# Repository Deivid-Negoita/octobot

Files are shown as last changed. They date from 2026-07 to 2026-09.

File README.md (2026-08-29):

# Octobot

An eight-legged walking robot with 24 servos, built end to end. The chassis and
legs are CAD. A custom ATmega32U4 board drives every servo. A browser workbench
rigs the CAD model and solves its inverse kinematics.

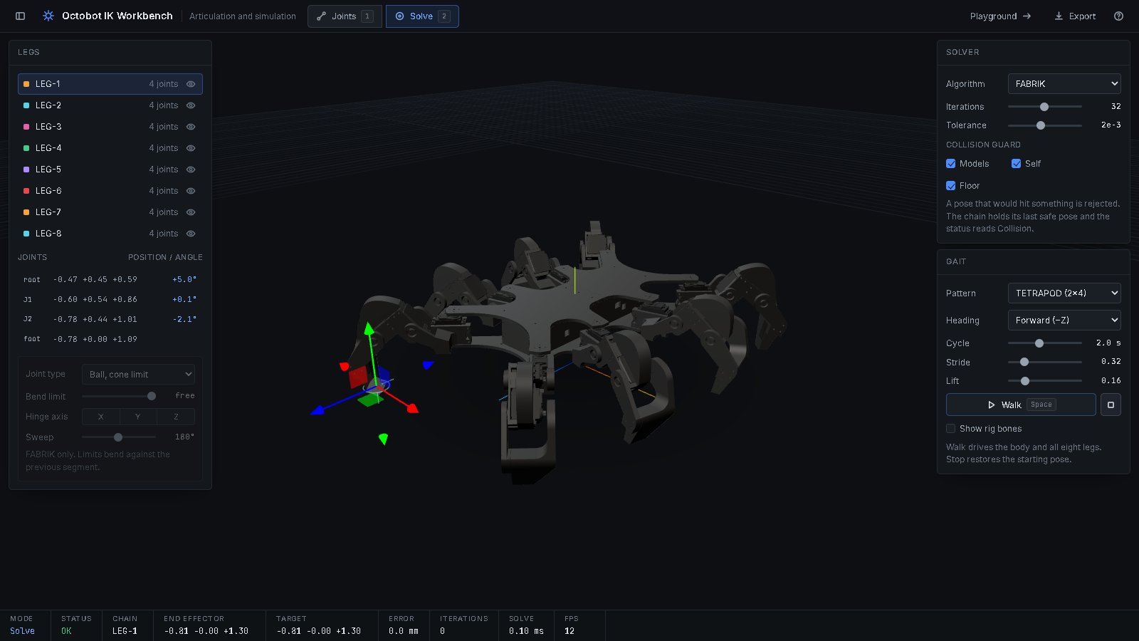
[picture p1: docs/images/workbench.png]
The IK workbench with the octobot rigged into eight legs


**The workbench runs live in the browser:
<https://deivid-negoita.github.io/octobot/>**. It needs no install and no
build step.

The robot carries environmental-monitoring, 3D-scanning and speleological
payloads. Those payloads need the legs to place feet accurately on uneven
ground, which a fixed gait cannot do. The kinematics workbench in this
repository exists to solve that.

---

## What is here

| Folder | Contents |
|---|---|
| [`kinematics/`](kinematics/) | Browser workbench and locomotion sandbox. Three.js, no build step. |
| [`hardware/`](hardware/) | KiCad 7 project for the 24-channel servo control board. |
| [`mechanical/`](mechanical/) | STEP exports of the chassis and a single leg. |
| [`docs/`](docs/) | [Hardware notes](docs/hardware.md), [kinematics notes](docs/kinematics.md) and the [bill of materials](docs/bom.md). |

The embedded firmware lives in a separate repository and is not included here.

---

## Run the kinematics workbench

The workbench runs in the browser with nothing to install:
**<https://deivid-negoita.github.io/octobot/>**. It is a static site, published
from `kinematics/` by `.github/workflows/pages.yml` on every push to `main`. A
fork gets its own copy after enabling **Settings → Pages → Source → GitHub
Actions** once.

To run it locally instead: the pages load ES modules, so they need an HTTP
server. Opening `index.html` from the filesystem gives you a blank screen and a
CORS error in the console.

```bash
cd kinematics/tools
python serve.py          # or double-click start.bat on Windows
```

Open <http://localhost:8123>. The chassis mesh is about 12 MB, so the first load
takes a few seconds. A progress bar reports the download.

Two pages share the model:

**`index.html`, the IK workbench.** The CAD model rigs itself on startup. The
loader finds the feet from the mesh geometry, then builds a hip-yaw →
shoulder-pitch → knee-pitch chain per leg on the real servo shaft axes. It binds
every servo, bracket and casing to the link it is screwed to. You get eight
chains named `LEG-1` to `LEG-8`. Drag the cyan target and that leg solves toward
it in real time while the servo angles update. Press `Space` to run a gait.

**`playground.html`, the locomotion sandbox.** Drive the robot with `W A S D` over
terrain blocks you spawn and drag. The feet land on the block surface or the
ground by analytic sampling, and the body rides at the average support height.
Live servo angles for all 24 joints stream into the telemetry panel.

| Key | Action |
|---|---|
| `1` / `2` | JOINTS / SOLVE mode (workbench) |
| `Space` | start or stop walking (workbench) |
| `H` | open the help card (workbench) |
| `P` | show or hide the panels (both pages) |
| `W A S D` | walk (playground) |
| `Q` / `E` | lower or raise the body (playground) |
| `Y` | toggle the onboard camera view (playground) |

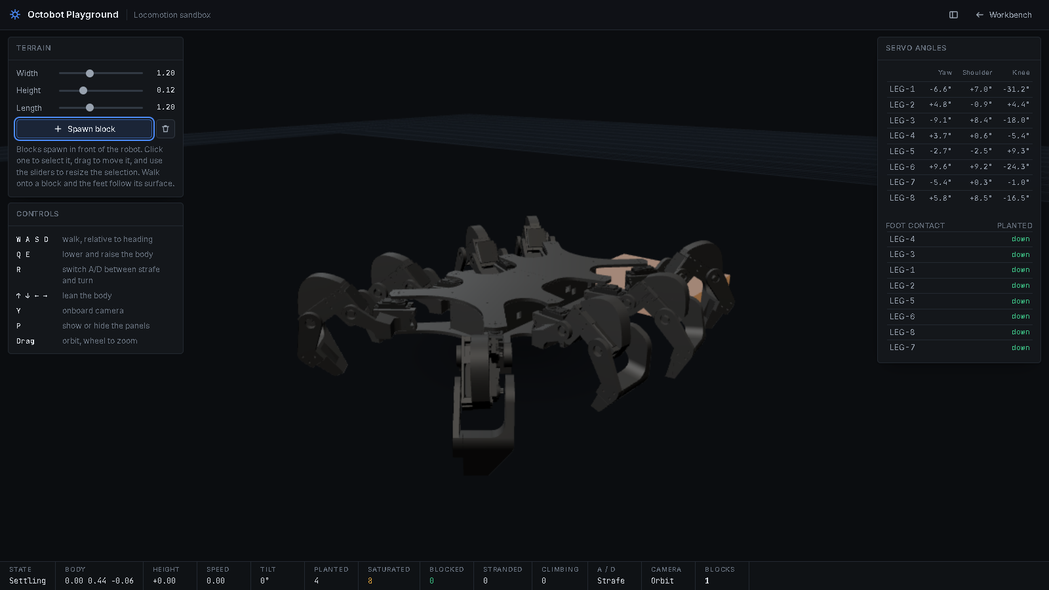
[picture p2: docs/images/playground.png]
Driving the octobot over a spawned terrain block


Read [`docs/kinematics.md`](docs/kinematics.md) for the solver, the collision
guard and the gait model.

---

## The control board

One board drives all 24 servos. An **ATmega32U4** talks over I²C to **two
PCA9685** 16-channel PWM drivers, which gives 32 channels for the 24 servos and
leaves headroom for sensors. An **SY8303** synchronous buck regulator supplies
the servo rail from the battery, and a P-channel MOSFET on the input protects
against reverse polarity.

The 24 servo headers sit on two separate power rails of 12, so the inrush of one
group of legs cannot brown out the other. An **HC-12** radio module plugs into a
4-pin header on D8 and D9. Running the link on a software UART keeps the
hardware USART free and lets the antenna sit away from the servo wiring. The
board is a 4-layer design with 120 placements, an AVR-ISP header, a DIP switch
and two tactile buttons.

Building 24 servo channels from discrete drivers would have cost more and taken
more board area than the two PCA9685s do.

`hardware/fabrication/` holds the package the board house was sent. It carries
gerbers for all four copper layers, both drill files, the IPC netlist, the
placement file and the BOM. Read [`docs/hardware.md`](docs/hardware.md) for the
rail split, the power path and the pin assignment of every header.

### Bill of materials

120 placements over 33 lines: 87 SMT and 33 through-hole. The table is read out of
the layout by [`hardware/tools/gen_bom.py`](hardware/tools/gen_bom.py) rather
than typed. `--check` re-groups the fabrication BOM the same way and compares it
designator by designator, so this list cannot quietly go stale:

```bash
python hardware/tools/gen_bom.py --check
120 placements match octobot-controller-bom.csv exactly.
```

<!-- BOM:START -->

| Qty | Value | Manufacturer part | Package | Ref | Function |
|---:|---|---|---|---|---|
| 2 | `PCA9685PW/Q900_118` | NXP | SOP65P640X110-28N | U1–U2 | 16-channel 12-bit PWM generator. 12 channels used each, at 0x40 and 0x41. |
| 1 | `ATmega32U4-M` | Microchip | QFN-44-1EP_7x7mm_P0.5mm_EP5.2x5.2mm | U3 | Host MCU. Native USB, 16 MHz crystal, I2C master. |
| 1 | `AVR-ISP` | — | AVR-ISP | U4 | ISP header on D14/D15/D16 and RESET. |
| 1 | `SY8303AIC` | Silergy | SOT65P280X110-8N | IC1 | Synchronous buck. VIN down to the 5.0 V logic rail set by R11/R12. |
| 3 | `LED` | — | LED_0201_0603Metric | D1, D3–D4 | Power, RX and TX indicators. |
| 1 | `4,7 uH` | Wurth Elektronik 7447713047 | 7447714220 | L1 | Buck output inductor. |
| 1 | `Crystal_GND24` | — | CRYSTAL-SMD-5X3.2-4PAD | Y1 | MCU clock, loaded by C1/C3. |
| 1 | `HPZR-C10X` | Nexperia | HPZRC10X | D5 | 10 V regulator diode. Clamps the pass FET gate. |
| 1 | `RQ3E075ATTB` | ROHM Semiconductor | RQ3E075ATTB | Q1 | P-channel MOSFET. Reverse-polarity pass element on the input. |
| 28 | `Conn_01x03_Pin` | — | PinHeader_1x03_P2.54mm_Vertical | J2–J8, J10–J14, J17–J30, J32–J33 | 24 servo headers (GND / rail / signal), 2 rail feeds (J29/J30), 2 analog headers (J32/J33). |
| 4 | `1x2` | — | PinHeader_1x02_P2.54mm_Vertical | J9, J16, J31, J34 | Input power (J9), 5 V taps (J16/J34), I2C breakout (J31). |
| 1 | `47346-0001` | Molex | MOLEX_47346-0001 | J1 | USB micro-B receptacle. Programming and 5 V input. |
| 1 | `Conn_01x04_Pin` | — | PinHeader_1x04_P2.54mm_Vertical | J15 | HC-12 radio header: 5 V, GND, D8, D9. |
| 2 | `TL3365AF180QG` | E-Switch | SW_TL3365AF180QG | S1–S2 | Reset (S1) and user button on D12 (S2). |
| 1 | `DS04-254-2-03BK-SMT` | CUI Devices | DS04254203BKSMT | S3 | 3-position DIP switch on D14/D15/D16. |
| 24 | `220 Ohm` | — | R_0603_1608Metric | R31–R54 | Series resistor on each servo signal line. |
| 20 | `10K` | — | R_0603_1608Metric | R1, R5, R8, R10, R14, R16–R30 | PWM address and OE straps, I2C pull-ups, buck enable. |
| 2 | `1K` | — | R_0402_1005Metric | R7, R9 | LED series resistors. |
| 2 | `22 Ohm` | — | R_0603_1608Metric | R2–R3 | USB D+/D- series termination. |
| 1 | `100K` | — | R_1206_3216Metric | R15 | Pass FET gate pull-down. |
| 1 | `100K Ohm` | — | R_0805_2012Metric | R13 | Buck switching-frequency set resistor. |
| 1 | `10KOhm` | — | R_0603_1608Metric | R4 | RESET pull-up. |
| 1 | `110K Ohm` | — | R_0805_2012Metric | R11 | Buck feedback divider, upper leg. |
| 1 | `15K Ohm` | — | R_0805_2012Metric | R12 | Buck feedback divider, lower leg. |
| 1 | `1KOhm` | — | R_0603_1608Metric | R6 | LED series resistor. |
| 6 | `10uF` | — | C_0805_2012Metric | C4–C5, C18–C19, C22–C23 | Rail decoupling. |
| 2 | `0,1uF` | — | C_0603_1608Metric | C17, C21 | Decoupling. |
| 2 | `18pF` | — | C_0603_1608Metric | C1, C3 | Crystal load capacitors. |
| 2 | `1uF` | — | C_0805_2012Metric | C2, C8 | USB UCAP and buck input decoupling. |
| 2 | `875075161013` | Wurth Elektronik | CAPAE1030X1240N | C6, C9 | Aluminium electrolytic. Bulk storage, one per servo rail. |
| 1 | `0.1uF` | — | C_0805_2012Metric | C7 | AREF decoupling. |
| 1 | `10nF` | — | C_1206_3216Metric | C20 | Buck bootstrap. |
| 1 | `12 pF` | — | C_1206_3216Metric | C16 | Buck feedback feed-forward. |

**120 placements over 33 lines: 87 SMT and 33 through-hole.**

<!-- BOM:END -->

Distributor part numbers are not tracked in the KiCad project, so an assembly
house needs those added at order time.

---

## Mechanical

`mechanical/` holds STEP exports of the assembled chassis and of a single leg.
Every part is 3D printed. The chassis was modelled in Autodesk Fusion 360, and
`kinematics/models/octobot.glb` is the mesh export the web app loads.

STEP files are text and compress to roughly 15% of their size, so the repository
carries the zips and ignores the loose exports. The chassis is 52 MB unpacked
and 7.7 MB zipped. Unzip before opening in CAD:

```bash
cd mechanical
unzip octobot-chassis.step.zip
```

---

## Tooling

`kinematics/tools/` holds the development scripts:

```bash
python serve.py          # static server with caching disabled
python verify.py         # drive both pages in Chromium, fail on any console error
python shots.py          # regenerate the README screenshots
```

`verify.py` and `shots.py` need Playwright:

```bash
pip install playwright && playwright install chromium
```

`verify.py` boots each page and asserts that the rig produced eight legs. It
then exercises the help modal, toggles the panels, runs the gait, spawns a
terrain block and walks the robot. It exits non-zero if the browser logged an
error.

---

## Built with

Three.js 0.160 loaded from a CDN, plain ES modules, no bundler and no
dependencies to install. KiCad 7 for the board. Autodesk Fusion 360 for the
mechanics.

## License

MIT. See [LICENSE](LICENSE).

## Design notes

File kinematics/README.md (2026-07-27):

# Kinematics workbench

Browser rig and IK solver for the octobot. Plain ES modules, Three.js 0.160 from
a CDN, no build step and nothing to install.

## Run it

ES modules cannot load over `file://`, so serve the folder:

```bash
cd tools
python serve.py          # or start.bat on Windows
```

Then open <http://localhost:8123>. An internet connection is needed for the
Three.js CDN and the fonts.

## Pages

- **`index.html`** — the workbench. The CAD model rigs itself into eight legs on
  startup. Inspect and constrain joints, drag the target to solve IK, run a gait,
  export the rig as JSON.
- **`playground.html`** — the locomotion sandbox. Drive with `W A S D` over
  terrain blocks you spawn and drag.

Press `H` in the workbench for the key map. Add `?debug` to the playground URL
for per-frame locomotion diagnostics in the console.

## Layout

```
css/     console.css holds the shared chrome; the other two are per page
js/      modules — see docs/kinematics.md for what each one does
models/  octobot.glb, the mesh the pages load (~12 MB)
tools/   serve.py, verify.py, shots.py, start.bat
```

## Development

```bash
cd tools
python serve.py &
python verify.py         # both pages in Chromium, fails on any console error
python shots.py          # regenerate the README screenshots
```

Both scripts need Playwright: `pip install playwright && playwright install chromium`.

The full write-up of the solvers, the collision guard and the gait model is in
[`../docs/kinematics.md`](../docs/kinematics.md).

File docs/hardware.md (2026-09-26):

# Controller board

A 124 × 23 mm four-layer board that drives 24 servos from a single MCU. It sits
along the spine of the chassis with twelve servo headers down each long edge, so
each leg's cable run is short.

Everything below is read from `hardware/octobot-controller.kicad_sch` and
`hardware/octobot-controller.kicad_pcb`. The files under
`hardware/fabrication/` are exported from that same layout, and
`python hardware/tools/gen_bom.py --check` compares the two designator by
designator.

| | |
|---|---|
| Outline | 124 × 23 mm, 1.6 mm, four copper layers |
| MCU | ATmega32U4 (QFN-44), 16 MHz crystal, native USB |
| PWM | 2 × NXP PCA9685, 12-bit, I2C |
| Servo channels | 24, on two independently supplied power rails |
| Input | 2-pin header, reverse-polarity protected, buck to 5 V |
| Radio | HC-12 module on a 4-pin header |
| Routing | 851 track segments, 97 vias, 3 copper zones |

---

## Power

Input arrives on `J9`. `Q1`, a ROHM RQ3E075ATTB P-channel MOSFET, passes it to
the `VIN` rail. `R15` (100 K) pulls the gate down, and `D5`, a Nexperia
HPZR-C10X 10 V regulator diode, clamps it. That pair blocks reverse polarity and
keeps the gate inside its rating on a higher-voltage pack.

`IC1`, a Silergy SY8303 synchronous buck, steps `VIN` down to the logic rail
through `L1` (4.7 µH). The feedback divider `R11`/`R12` (110 K / 15 K) against
the part's 0.6 V reference sets the output to 5.0 V. `R13` sets the switching
frequency, `R14` ties `EN` high off `VIN`, and `C20` is the bootstrap.

The 5 V rail supplies the MCU, both PWM expanders, the radio header, the ISP
header, the two analog sensor headers, and the `J16`/`J34` taps.

### Servo rails are separate

`VCC_SERVOBLOCK_1` and `VCC_SERVOBLOCK_2` never touch the 5 V logic rail. Each
is fed only through pin 2 of its rail header, `J29` for rail 1 and `J30` for
rail 2. Each also carries a Würth 875075161013 aluminium electrolytic (`C6`,
`C9`) for the stall-current transients that twelve servos produce.

Those headers are wired GND / rail / `VIN`, which gives two options per rail:

- Jumper pin 2 to pin 3 to run that block of servos straight off the input pack.
- Leave the jumper off and feed pin 2 from a separate BEC.

Two independently fed rails keep one leg group's current spikes out of the
other, and keep both out of the logic supply.

### Which servo voltage

Feed both servo rails at 6.0 V. The MG996R is rated 9.4 kgf·cm at 4.8 V and
11 kgf·cm at 6.0 V, which is 0.92 and 1.08 N·m.

The OmniLink team ran the gait in their simulator at both points. The results
are theirs, not measured on the robot:

| Servo torque | 1.08 N·m (6.0 V) | 0.92 N·m (4.8 V) |
|---|---|---|
| Flat-ground travel lost | 2.8 % | 4.3 % |
| Margin over the collapse point | 1.8× | 1.5× |

Both voltages walk. Sweeping the torque down, the gait stops working between
0.35 and 0.42 N·m on flat ground and between 0.50 and 0.60 N·m climbing a 48 mm
block, so the block sets the limit.

Their run assumed a 3.0 kg robot, because the BOM covers only the electronics
and the STEP solids are not watertight. By their extrapolation, the block gait
runs out of margin near 5.4 kg at 6 V or 4.6 kg at 4.8 V. **Weigh the assembled
robot.** That one figure would change these margins more than any other input.

## Servo channels

24 three-pin headers, each wired GND / rail / signal:

| Rail | Headers | PWM device |
|---|---|---|
| `VCC_SERVOBLOCK_1` | `J2`–`J8`, `J10`–`J14` | `U1` at 0x40 |
| `VCC_SERVOBLOCK_2` | `J17`–`J28` | `U2` at 0x41 |

Every signal line runs through a 220 Ω series resistor (`R31`–`R54`) between the
PCA9685 output and the header pin. The resistor damps the reflections a long,
unshielded servo lead produces. It also limits the current into the servo's
input on a fault.

`U1` takes the base address with `A0`–`A5` pulled to ground through 10 K. `U2`
ties `A0` to 5 V for 0x41. Each device drives channels 0 to 11, so channels 12 to
15 are left unconnected — 8 spare channels for a future revision. `OE` on both is
pulled low through 10 K so outputs are enabled at power-up.

## Interfaces

| Header | Pins | Purpose |
|---|---|---|
| `J1` | Molex 47346-0001 | USB micro-B. Programming, and 5 V in when bench-powered. |
| `J15` | 5 V, GND, `D8`, `D9` | HC-12 radio module. `D8`/`D9` carry the serial pair. |
| `J31` | `D2`, `D3` | I2C breakout, the same bus the PWM expanders sit on. |
| `J32`, `J33` | GND, 5 V, `A0` / `A1` | Analog sensor headers. |
| `J16`, `J34` | GND, 5 V | 5 V taps. |
| `U4` | 6-pin AVR ISP | `RESET`, `D14`/MISO, `D15`/SCK, `D16`/MOSI. |

The MCU can be programmed over USB through the bootloader or over ISP at `U4`.
`S3`, a three-position DIP switch, shares `D14`/`D15`/`D16` with the ISP header,
so open it before programming through `U4`.

I2C runs on `D2` (SDA) and `D3` (SCL) with 10 K pull-ups to 5 V.

## Controls and indicators

| Part | Function |
|---|---|
| `S1` | Reset. Tactile, on `RESET` with a 10 K pull-up (`R4`). |
| `S2` | User button on `D12`, 10 K pull-down (`R8`). |
| `S3` | 3-position DIP switch on `D14`/`D15`/`D16`. |
| `D1` | Power. Straight off 5 V through `R7`. |
| `D3`, `D4` | Serial activity, driven from `D17` and `PD5`. |

## Bill of materials

[bom.md](bom.md) — generated from the project files, 120 placements over 33
lines. Regenerate with `python hardware/tools/gen_bom.py --write`.

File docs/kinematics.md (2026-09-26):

# Kinematics

The workbench answers one question for the physical robot:

> **Given a foot position, what angle does each of the three servos in that leg
> need?**

That is the inverse kinematics problem. The browser is a convenient place to
solve it because the CAD model already contains the geometry.

Two pages share the model and take different approaches to it.

---

## Auto-rigging

Nothing is rigged by hand. `index.html` loads `models/octobot.glb` and derives
the skeleton from the mesh.

**1. Find the feet.** `detectFeet` samples every mesh vertex that sits within
0.07 units of the ground plane. It then clusters those contacts in XZ with a
radius that scales to the model. The eight largest clusters are the feet.
Sampling is strided so a 12 MB mesh stays fast.

**2. Build a chain per foot.** Each foot gets a hip-yaw → shoulder-pitch →
knee-pitch chain. The joint pivots come from the servo geometry rather than from
a guess. The pivot is the centre of the servo **head** mesh, because the horn
sits exactly on the shaft axis. Anchoring there makes the servo body rotate
around its own head, so head and body stay coaxial through the full sweep.
Bounding-box overlap is only the fallback for a servo with no separate head.

**3. Bind the parts.** `binding.js` assigns every top-level CAD occurrence to a
bone by centroid distance. The `art_1/2/3` links go to their exact bones by CAD
name. Servos, casings and brackets go to the link they are screwed to, chosen by
maximum mesh overlap. Chassis and electronics ride with the body.

The bound occurrences are reparented into per-bone groups that follow the solved
bones every frame. The real printed parts articulate, rather than a stick figure.

---

## Solvers

`solver.js` implements two, selectable at runtime.

**FABRIK** (Forward And Backward Reaching Inverse Kinematics) is the default. It
walks the chain backward from the target to the root, then forward from the root
to the target. It repeats that pass until the end effector is within tolerance.
FABRIK converges in few iterations. It is also the only solver here that honours
joint constraints.

**CCD** (Cyclic Coordinate Descent) rotates one joint at a time to point the end
effector at the target, iterating down the chain. It is included for comparison.
CCD ignores the constraints, which is exactly why the workbench shows both:
switching to CCD makes the value of the constraint pass obvious.

### Constraints

Two joint types:

- **Ball with cone limit.** The outgoing bone direction is clamped so its angle
  to the previous segment never exceeds a set maximum.
- **Hinge.** A single-axis servo joint. The auto-rig gives each joint a custom
  axis in the leg frame, taken from the real servo shaft. Picking X, Y or Z in
  the inspector overrides that. The sweep is centred on the rest pose, which is
  what a servo horn mounted at its midpoint actually does.

The physical joint limits are in `octorig.js`:

```js
export const LIMITS = { yaw: 0.55, shoulder: Math.PI / 2, knee: Math.PI / 2 };
```

These are the ranges the linkage sweeps before the brackets foul, not the
servo's full travel. Widening the yaw limit to ±90° was tried and measured. It
put 43% to 55% of frames past 60°, with shoulder and knee pinned at the stop,
and produced folded, curled leg poses. The tighter values cost nothing
measurable — identical climb heights, walking distance within 3% — and cut the
deepest mesh penetration from 153 mm to 61 mm.

The shoulder limit is the one that binds on a step. In OmniLink's simulation
of a fixed-height gait, climbing a 48 mm block used the full shoulder range
(1.000 of the limit above), against 0.37 on flat ground. That held at 0.92,
1.08 and 1.50 N·m alike. So this is a position limit, not a torque one:
with body height fixed, the climb has to come from the shoulder. The knees never
used more than 53 % of their range. The playground raises the body over
terrain, which spreads that climb across the legs.

---

## Collision guard

A pose that drives a bone through the chassis, through another bone of the same
leg, or below the floor is **rejected**. The leg freezes at its last accepted
pose, the offending bones and the target turn red, and STATUS reads `COLLISION`.

The interesting part is the baseline. The rig places joints inside the model it
is rigging, so a naive check reports a collision on the very first frame and
never recovers. Instead every contact gets a stable flag — `m3:b1`, `floor:b2`,
`self:0:2` — and the chain keeps the flag set of its last accepted pose. Only a
**new** flag blocks. Contacts that already existed when a pose was accepted are
treated as intentional. Toggling a guard re-baselines from the current pose.

Bone-to-bone distance uses the standard closest-point-between-segments routine
(Ericson, *Real-Time Collision Detection* 5.1.9). Segment ends are trimmed by
0.045 units because joints legitimately sit on surfaces.

---

## Gait

`gait.js` cycles each leg through **stance** and **swing**. During stance the
foot is pinned to a world position while the body passes over it. During swing
the foot lifts along an arc and reaches forward.

The body advances at:

```
v = stride / (duty × cycleTime)
```

That speed is what makes stance feet stationary in world space. Get it wrong and
the robot moonwalks — the legs cycle but the feet skate. Measured drift with the
correct speed is under 2 mm per step.

Two patterns:

| Pattern | Duty | Behaviour |
|---|---|---|
| Tetrapod | 0.5 | Two alternating groups of four |
| Wave | 0.75 | A ripple around the body |

The playground uses closed-form IK instead of an iterative solver: yaw plus a
two-link planar solution per leg. Parts cannot detach and the solve is exact.
Hinge signs are calibrated at load by probing each servo. The sign depends on
how the servo is mounted, and the CAD does not record that.

### Reading a gait log

Two signals from OmniLink's torque sweep are worth checking before trusting a
run:

- **A stalled gait still reports finished.** Below the collapse torque the
  robot stays upright and stops moving. A completion flag is not evidence that
  it walked, so check the distance travelled.
- **Minimum support contacts show weak servos first.** The minimum rose from 0
  to 2 to 8 feet on the ground as torque fell from 1.50 to 1.08 to 0.92 N·m.
  The swing legs could not lift clear. This shows up before the distance
  number moves much.

---

## Export

**EXPORT** downloads the rig as JSON: legs, joints, hinge axes, limits, solver
settings and the current servo angles. That file is the handoff to the firmware
on the real controller.

---

## Source map

| File | Responsibility |
|---|---|
| `js/main.js` | Scene, app state, interaction, render loop, auto-rig |
| `js/chain.js` | `KinematicChain` — joints, bone visuals, target, solve calls |
| `js/solver.js` | FABRIK, CCD, hinge chains, constraint enforcement |
| `js/collision.js` | Bone/model, self and floor checks with flag baselining |
| `js/binding.js` | Binds CAD occurrences to rig bones |
| `js/gait.js` | Stance/swing cycling and body translation |
| `js/octorig.js` | Playground rig: true transform hierarchy, closed-form IK |
| `js/playground.js` | Playground scene, driving, terrain, telemetry |
| `js/loader.js` | GLB/GLTF/OBJ/STL/STEP import and normalization |
| `js/boot.js` | Startup overlay and progress-reporting fetch |
| `js/ui.js` | Panels, lists, telemetry, export |

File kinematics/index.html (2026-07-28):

# Octobot IK Workbench

Articulation and simulation

Fetching mesh

The chassis mesh is about 12 MB. It loads once, then rigs itself into eight servo-driven legs.

# Octobot IK Workbench

Articulation and simulation

Joints 1 Solve 2

Playground Export

## Legs

Joints position / angle

Joint type

Bend limit free

Hinge axis

XYZ

Sweep 180°

FABRIK only. Limits bend against the previous segment.

## Solver

Algorithm

Iterations 16

Tolerance 2e-3

Collision guard

Models Self Floor

A pose that would hit something is rejected. The chain holds its last safe pose and the status reads Collision.

## Gait

Pattern

Heading

Cycle 2.0 s

Stride 0.45

Lift 0.20

Walk Space

Show rig bones

Walk drives the body and all eight legs. Stop restores the starting pose.

ModeSolve

StatusOK

Chain—

End effector—

Target—

Error—

Iterations—

Solve—

FPS—

### Octobot IK workbench

Startup | The octobot loads and rigs itself: eight legs, each a hip-yaw → shoulder-pitch → knee-pitch chain on the real servo axes, with every mesh bound to the link it is screwed to.
Joints 1 | Click a leg in the list or a joint in the scene to select it. The inspector shows that servo's type, hinge axis and sweep limit. The joint list streams live position and angle.
Solve 2 | Drag the target. That leg solves toward it in real time and the servo angles update live.
Gait Space | Pick a pattern and heading, then Walk to drive all eight legs. Stop restores the pose. Show rig bones reveals the skeleton inside the mesh.
Collision | Poses that would drive a link through the chassis, another link, or the floor are rejected. The leg holds its last safe pose and the offending links turn red.
Export | Downloads the rig and the current servo angles as JSON for the controller.
Camera | Drag to orbit, wheel to zoom, right-drag to pan. F re-frames the robot, P hides the panels.

Press Esc to close. Close

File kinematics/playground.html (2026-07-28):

# Octobot Playground

Locomotion sandbox

Fetching mesh

The chassis mesh is about 12 MB. Once it loads, each servo is probed to calibrate its hinge sign, then the stance is measured against the floor.

# Octobot Playground

Locomotion sandbox

Workbench

## Terrain

Width 1.20

Height 0.12

Length 1.20

Spawn block

Blocks spawn in front of the robot. Click one to select it, drag to move it, and use the sliders to resize the selection. Walk onto a block and the feet follow its surface.

## Controls

W A S D walk, relative to heading

Q E lower and raise the body

R switch A/D between strafe and turn

↑ ↓ ← → lean the body

Y onboard camera

P show or hide the panels

Drag orbit, wheel to zoom

## Servo angles

Live servo angles per leg
Leg | Yaw | Shoulder | Knee

StateBoot

Body—

Height+0.00

Speed0.00

Tilt0°

Planted8

Saturated0

Blocked0

Stranded0

Climbing0

A / DStrafe

CameraOrbit

Blocks0

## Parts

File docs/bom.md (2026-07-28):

# Bill of materials

Generated from the KiCad project by `hardware/tools/gen_bom.py` — placements and
packages from `octobot-controller.kicad_pcb`, manufacturer part numbers from
`octobot-controller.kicad_sch`. Do not edit by hand:

```bash
python hardware/tools/gen_bom.py --write   # regenerate this file and the README
python hardware/tools/gen_bom.py --check   # confirm it matches the fab export
```

`--check` compares this table against
`hardware/fabrication/octobot-controller-bom.csv`, the BOM inside the
fabrication package the board house was sent. The two agree line for line and
designator for designator.

Distributor part numbers are not tracked in the project files, so an assembly
house needs those added at order time.

---

| Qty | Value | Manufacturer part | Package | Ref | Function |
|---:|---|---|---|---|---|
| 2 | `PCA9685PW/Q900_118` | NXP | SOP65P640X110-28N | U1–U2 | 16-channel 12-bit PWM generator. 12 channels used each, at 0x40 and 0x41. |
| 1 | `ATmega32U4-M` | Microchip | QFN-44-1EP_7x7mm_P0.5mm_EP5.2x5.2mm | U3 | Host MCU. Native USB, 16 MHz crystal, I2C master. |
| 1 | `AVR-ISP` | — | AVR-ISP | U4 | ISP header on D14/D15/D16 and RESET. |
| 1 | `SY8303AIC` | Silergy | SOT65P280X110-8N | IC1 | Synchronous buck. VIN down to the 5.0 V logic rail set by R11/R12. |
| 3 | `LED` | — | LED_0201_0603Metric | D1, D3–D4 | Power, RX and TX indicators. |
| 1 | `4,7 uH` | Wurth Elektronik 7447713047 | 7447714220 | L1 | Buck output inductor. |
| 1 | `Crystal_GND24` | — | CRYSTAL-SMD-5X3.2-4PAD | Y1 | MCU clock, loaded by C1/C3. |
| 1 | `HPZR-C10X` | Nexperia | HPZRC10X | D5 | 10 V regulator diode. Clamps the pass FET gate. |
| 1 | `RQ3E075ATTB` | ROHM Semiconductor | RQ3E075ATTB | Q1 | P-channel MOSFET. Reverse-polarity pass element on the input. |
| 28 | `Conn_01x03_Pin` | — | PinHeader_1x03_P2.54mm_Vertical | J2–J8, J10–J14, J17–J30, J32–J33 | 24 servo headers (GND / rail / signal), 2 rail feeds (J29/J30), 2 analog headers (J32/J33). |
| 4 | `1x2` | — | PinHeader_1x02_P2.54mm_Vertical | J9, J16, J31, J34 | Input power (J9), 5 V taps (J16/J34), I2C breakout (J31). |
| 1 | `47346-0001` | Molex | MOLEX_47346-0001 | J1 | USB micro-B receptacle. Programming and 5 V input. |
| 1 | `Conn_01x04_Pin` | — | PinHeader_1x04_P2.54mm_Vertical | J15 | HC-12 radio header: 5 V, GND, D8, D9. |
| 2 | `TL3365AF180QG` | E-Switch | SW_TL3365AF180QG | S1–S2 | Reset (S1) and user button on D12 (S2). |
| 1 | `DS04-254-2-03BK-SMT` | CUI Devices | DS04254203BKSMT | S3 | 3-position DIP switch on D14/D15/D16. |
| 24 | `220 Ohm` | — | R_0603_1608Metric | R31–R54 | Series resistor on each servo signal line. |
| 20 | `10K` | — | R_0603_1608Metric | R1, R5, R8, R10, R14, R16–R30 | PWM address and OE straps, I2C pull-ups, buck enable. |
| 2 | `1K` | — | R_0402_1005Metric | R7, R9 | LED series resistors. |
| 2 | `22 Ohm` | — | R_0603_1608Metric | R2–R3 | USB D+/D- series termination. |
| 1 | `100K` | — | R_1206_3216Metric | R15 | Pass FET gate pull-down. |
| 1 | `100K Ohm` | — | R_0805_2012Metric | R13 | Buck switching-frequency set resistor. |
| 1 | `10KOhm` | — | R_0603_1608Metric | R4 | RESET pull-up. |
| 1 | `110K Ohm` | — | R_0805_2012Metric | R11 | Buck feedback divider, upper leg. |
| 1 | `15K Ohm` | — | R_0805_2012Metric | R12 | Buck feedback divider, lower leg. |
| 1 | `1KOhm` | — | R_0603_1608Metric | R6 | LED series resistor. |
| 6 | `10uF` | — | C_0805_2012Metric | C4–C5, C18–C19, C22–C23 | Rail decoupling. |
| 2 | `0,1uF` | — | C_0603_1608Metric | C17, C21 | Decoupling. |
| 2 | `18pF` | — | C_0603_1608Metric | C1, C3 | Crystal load capacitors. |
| 2 | `1uF` | — | C_0805_2012Metric | C2, C8 | USB UCAP and buck input decoupling. |
| 2 | `875075161013` | Wurth Elektronik | CAPAE1030X1240N | C6, C9 | Aluminium electrolytic. Bulk storage, one per servo rail. |
| 1 | `0.1uF` | — | C_0805_2012Metric | C7 | AREF decoupling. |
| 1 | `10nF` | — | C_1206_3216Metric | C20 | Buck bootstrap. |
| 1 | `12 pF` | — | C_1206_3216Metric | C16 | Buck feedback feed-forward. |

**120 placements over 33 lines — 87 SMT, 33 through-hole.**

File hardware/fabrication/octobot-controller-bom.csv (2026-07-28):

designator | quantity | value | pack | mpn | mount_type
C1, C3 | 2 | 18pF | C_0603_1608Metric |  | smt
C16 | 1 | 12 pF | C_1206_3216Metric |  | smt
C17, C21 | 2 | 0,1uF | C_0603_1608Metric |  | smt
C18, C19, C22, C23, C4, C5 | 6 | 10uF | C_0805_2012Metric |  | smt
C2, C8 | 2 | 1uF | C_0805_2012Metric |  | smt
C20 | 1 | 10nF | C_1206_3216Metric |  | smt
C6, C9 | 2 | 875075161013 | CAPAE1030X1240N |  | smt
C7 | 1 | 0.1uF | C_0805_2012Metric |  | smt
D1, D3, D4 | 3 | LED | LED_0201_0603Metric |  | smt
D5 | 1 | HPZR-C10X | HPZRC10X |  | smt
IC1 | 1 | SY8303AIC | SOT65P280X110-8N |  | smt
J1 | 1 | 47346-0001 | MOLEX_47346-0001 |  | smt
J10, J11, J12, J13, J14, J17, J18, J19, J2, J20, J21, J22, J23, J24, J25, J26, J27, J28, J29, J3, J30, J32, J33, J4, J5, J6, J7, J8 | 28 | Conn_01x03_Pin | PinHeader_1x03_P2.54mm_Vertical |  | tht
J15 | 1 | Conn_01x04_Pin | PinHeader_1x04_P2.54mm_Vertical |  | tht
J16, J31, J34, J9 | 4 | 1x2 | PinHeader_1x02_P2.54mm_Vertical |  | tht
L1 | 1 | 4,7 uH | 7447714220 |  | smt
Q1 | 1 | RQ3E075ATTB | RQ3E075ATTB |  | smt
R1, R10, R14, R16, R17, R18, R19, R20, R21, R22, R23, R24, R25, R26, R27, R28, R29, R30, R5, R8 | 20 | 10K | R_0603_1608Metric |  | smt
R11 | 1 | 110K Ohm | R_0805_2012Metric |  | smt
R12 | 1 | 15K Ohm | R_0805_2012Metric |  | smt
R13 | 1 | 100K Ohm | R_0805_2012Metric |  | smt
R15 | 1 | 100K | R_1206_3216Metric |  | smt
R2, R3 | 2 | 22 Ohm | R_0603_1608Metric |  | smt
R31, R32, R33, R34, R35, R36, R37, R38, R39, R40, R41, R42, R43, R44, R45, R46, R47, R48, R49, R50, R51, R52, R53, R54 | 24 | 220 Ohm | R_0603_1608Metric |  | smt
R4 | 1 | 10KOhm | R_0603_1608Metric |  | smt
R6 | 1 | 1KOhm | R_0603_1608Metric |  | smt
R7, R9 | 2 | 1K | R_0402_1005Metric |  | smt
S1, S2 | 2 | TL3365AF180QG | SW_TL3365AF180QG |  | smt
S3 | 1 | DS04-254-2-03BK-SMT | DS04254203BKSMT |  | smt
U1, U2 | 2 | PCA9685PW/Q900_118 | SOP65P640X110-28N |  | smt
U3 | 1 | ATmega32U4-M | QFN-44-1EP_7x7mm_P0.5mm_EP5.2x5.2mm |  | smt
U4 | 1 | AVR-ISP | AVR-ISP |  | tht
Y1 | 1 | Crystal_GND24 | CRYSTAL-SMD-5X3.2-4PAD |  | smt

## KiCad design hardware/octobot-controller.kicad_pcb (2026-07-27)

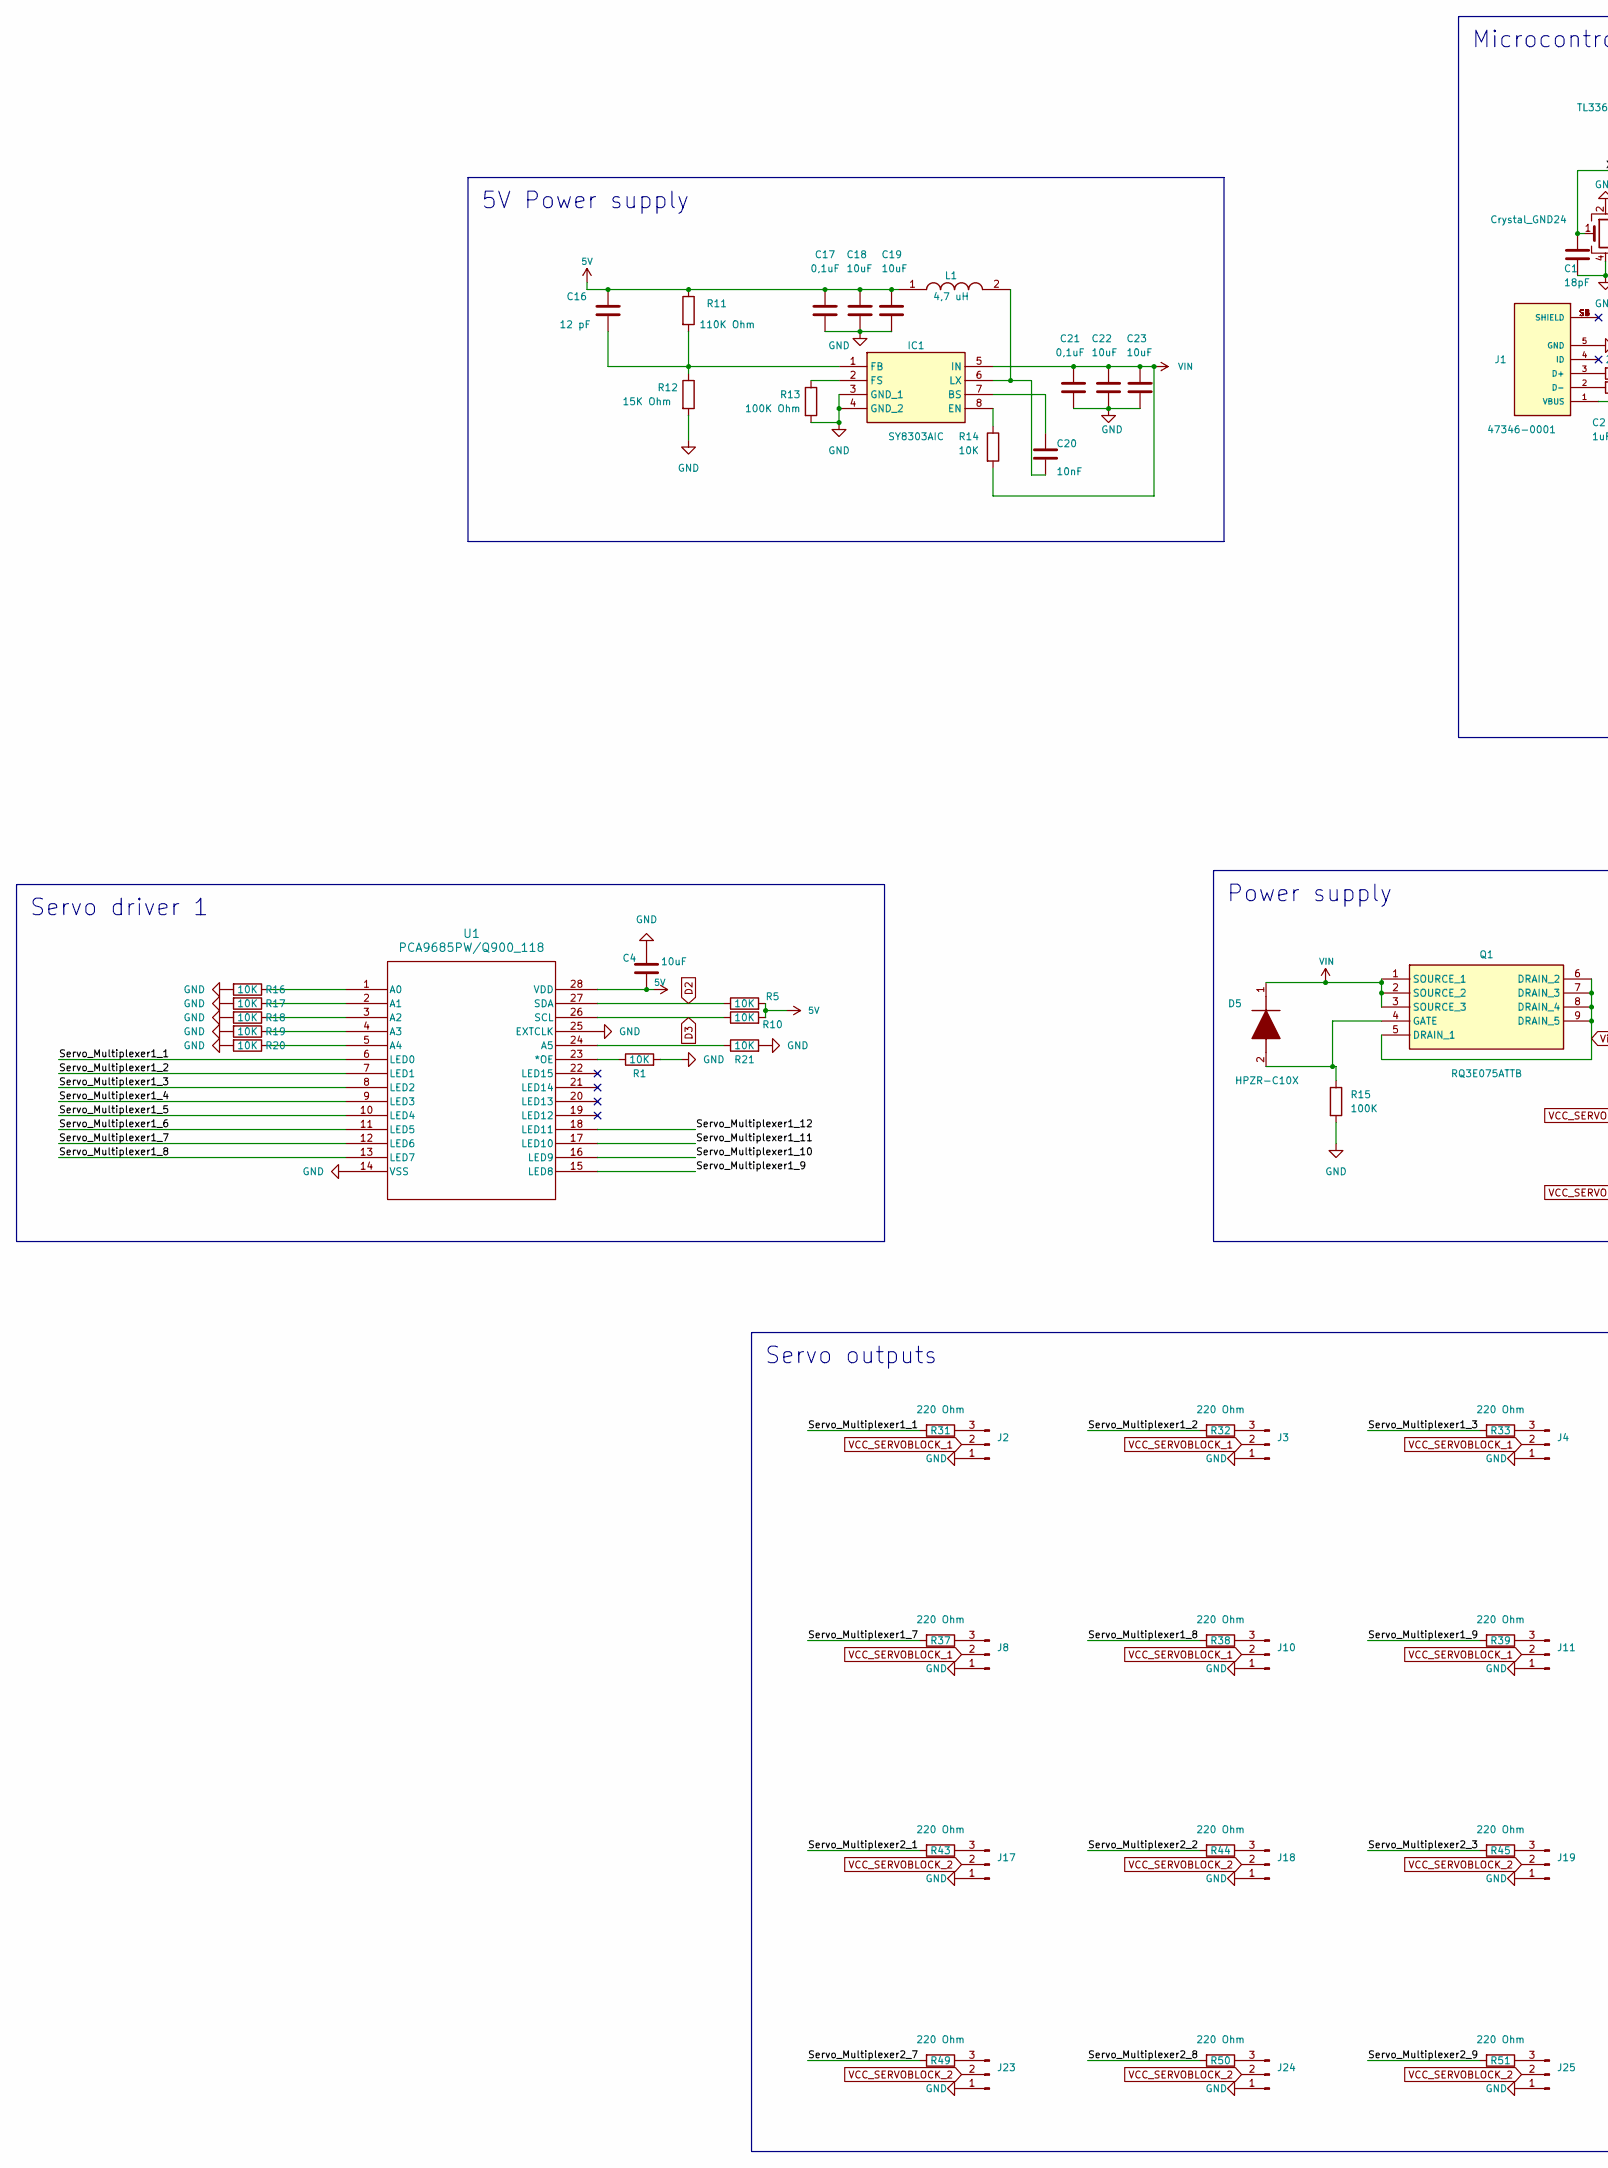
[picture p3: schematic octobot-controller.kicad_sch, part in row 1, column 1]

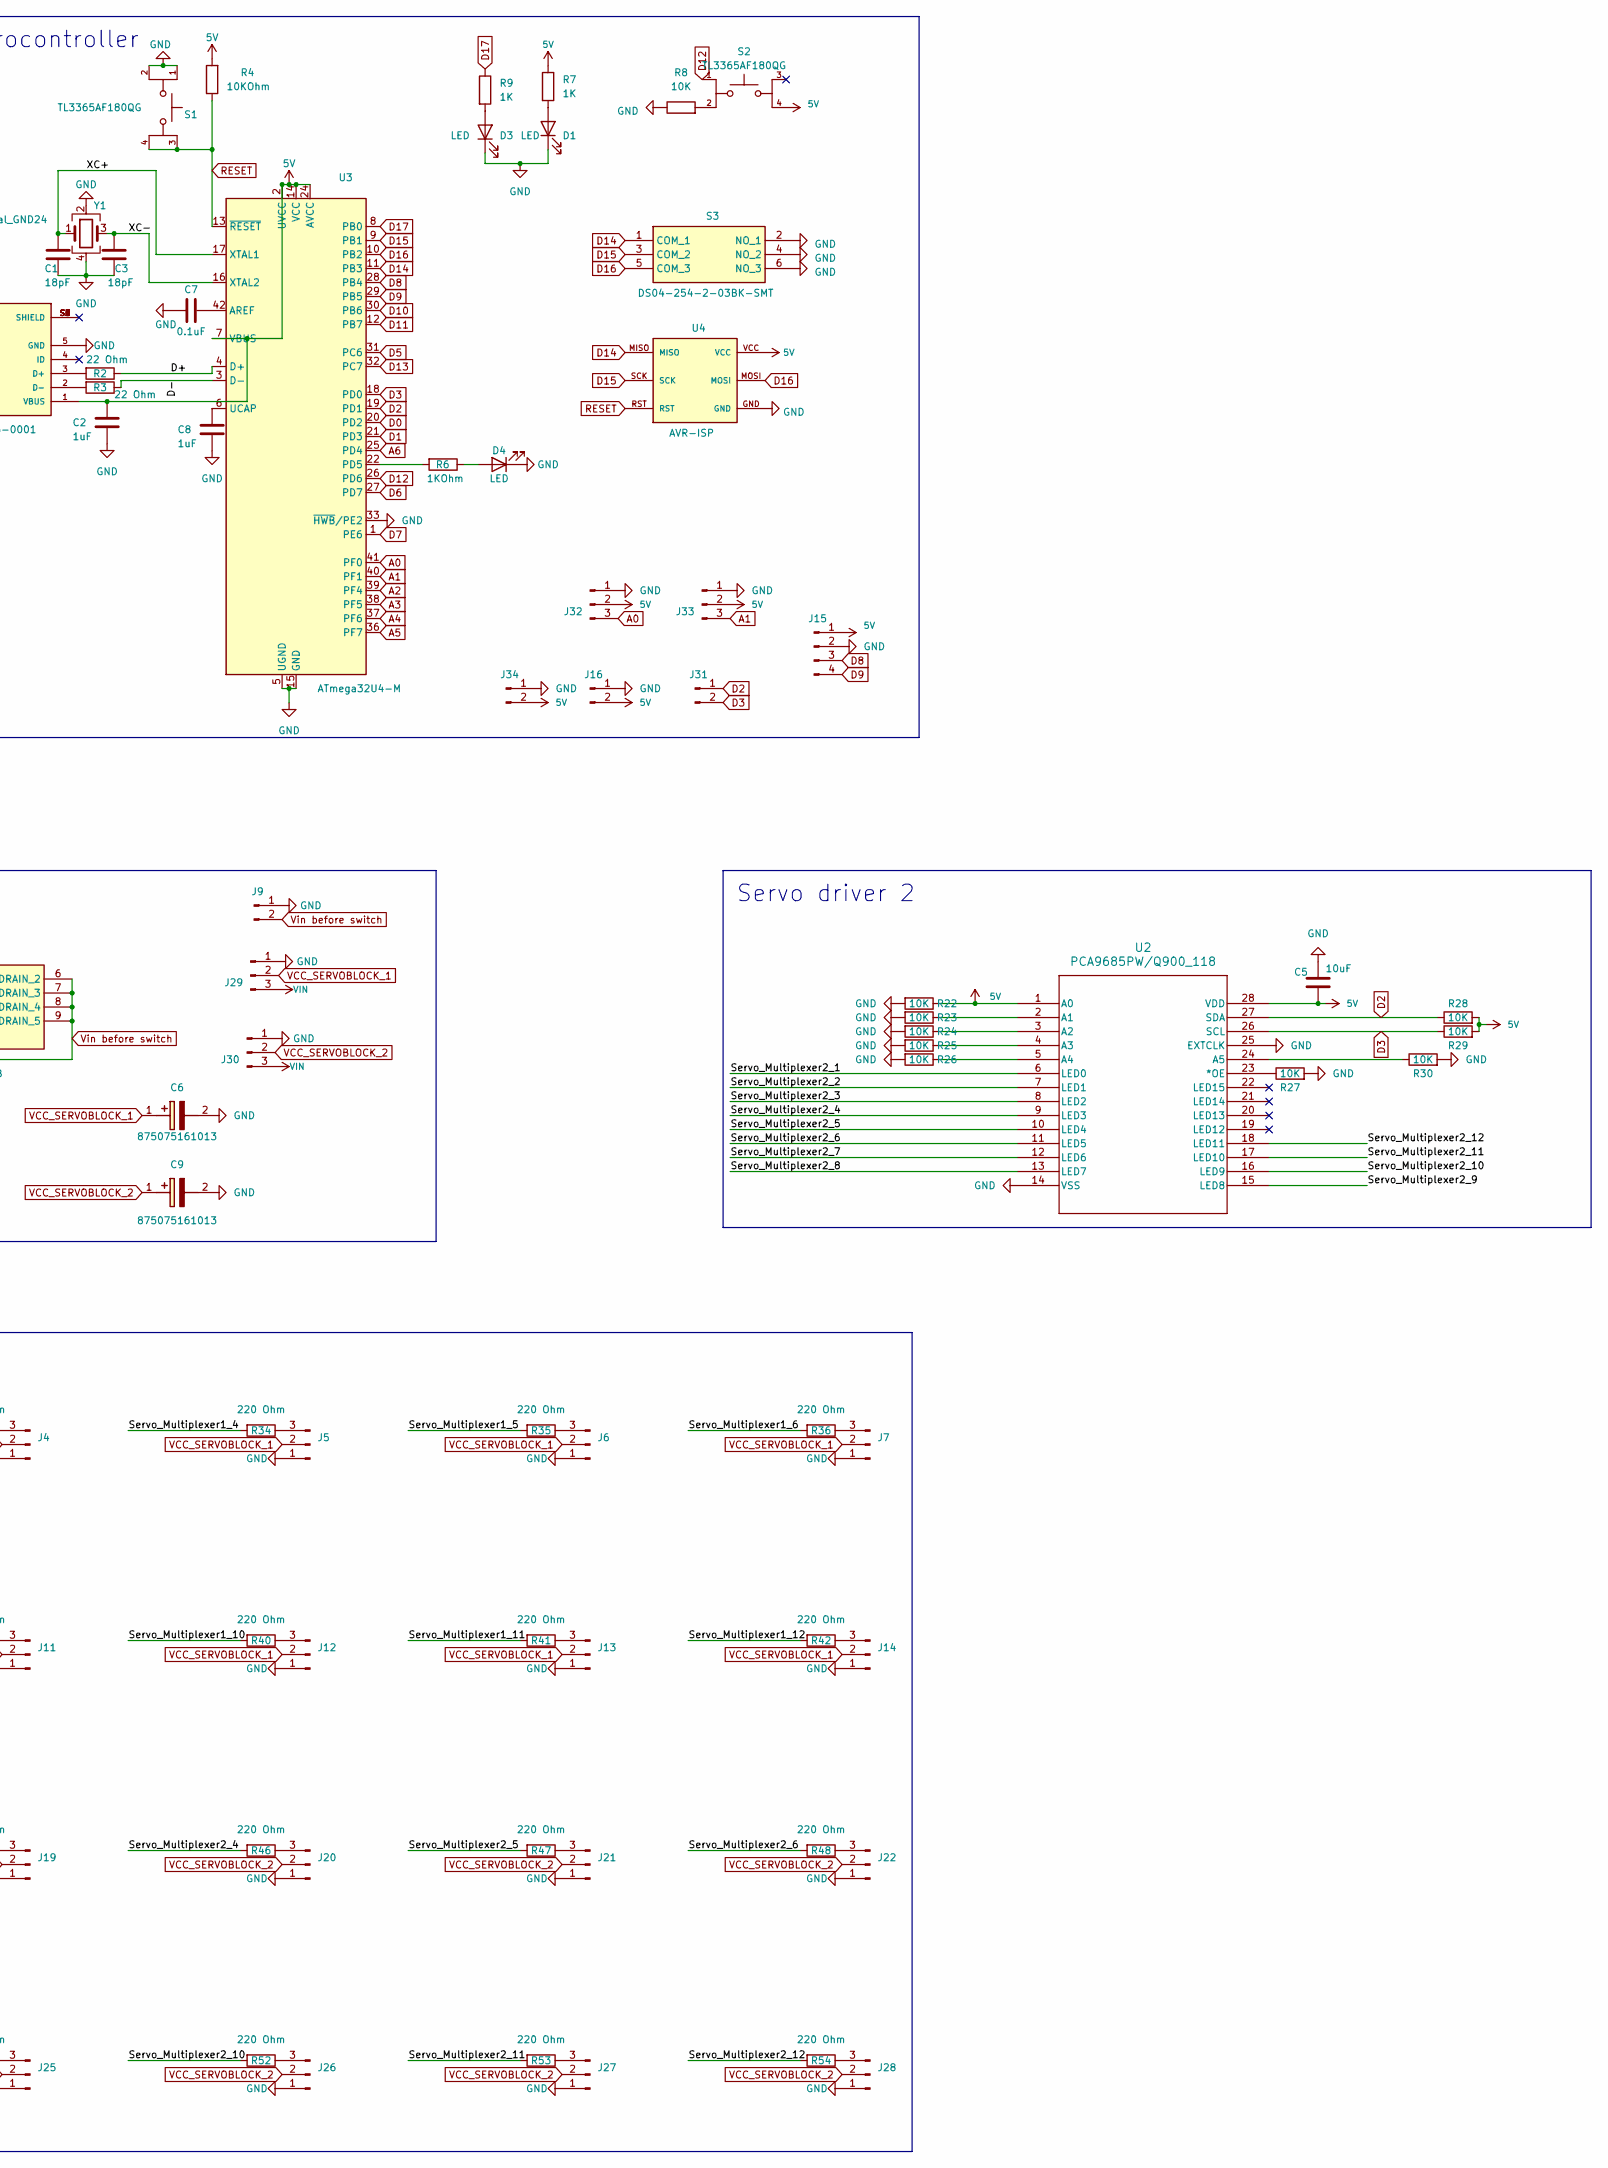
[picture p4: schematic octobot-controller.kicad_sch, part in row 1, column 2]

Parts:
C1, C3: 18pF; C_0603_1608Metric
C2, C8: 1uF; C_0805_2012Metric
C4, C5, C18, C19, C22, C23: 10uF; C_0805_2012Metric
C6, C9: 875075161013; CAPAE1030X1240N; Manufacturer_Part_Number 875075161013; Mouser Part Number 710-875075161013
C7: 0.1uF; C_0805_2012Metric
C16: 12 pF; C_1206_3216Metric
C17, C21: 0,1uF; C_0603_1608Metric
C20: 10nF; C_1206_3216Metric
D1, D3, D4: LED; LED_0201_0603Metric
D5: HPZR-C10X; HPZRC10X; Mouser Part Number 771-HPZR-C10X
IC1: SY8303AIC; SOT65P280X110-8N; Manufacturer_Part_Number SY8303AIC
J1: 47346-0001; MOLEX_47346-0001; PARTREV E
J2, J3, J4, J5, J6, J7, J8, J10, J11, J12, J13, J14, J17, J18, J19, J20, J21, J22, J23, J24, J25, J26, J27, J28, J29, J30, J32, J33: Conn_01x03_Pin; PinHeader_1x03_P2.54mm_Vertical
J9, J16, J31, J34: 1x2; PinHeader_1x02_P2.54mm_Vertical
J15: Conn_01x04_Pin; PinHeader_1x04_P2.54mm_Vertical
L1: 4,7 uH; 7447714220; Mouser Part Number 710-7447713047
Q1: RQ3E075ATTB; Mouser Part Number 755-RQ3E075ATTB
R1, R5, R8, R10, R14, R16, R17, R18, R19, R20, R21, R22, R23, R24, R25, R26, R27, R28, R29, R30: 10K; R_0603_1608Metric
R2, R3: 22 Ohm; R_0603_1608Metric
R4: 10KOhm; R_0603_1608Metric
R6: 1KOhm; R_0603_1608Metric
R7, R9: 1K; R_0402_1005Metric
R11: 110K Ohm; R_0805_2012Metric
R12: 15K Ohm; R_0805_2012Metric
R13: 100K Ohm; R_0805_2012Metric
R15: 100K; R_1206_3216Metric
R31, R32, R33, R34, R35, R36, R37, R38, R39, R40, R41, R42, R43, R44, R45, R46, R47, R48, R49, R50, R51, R52, R53, R54: 220 Ohm; R_0603_1608Metric
S1, S2: TL3365AF180QG; SW_TL3365AF180QG; PARTREV A
S3: DS04-254-2-03BK-SMT; DS04254203BKSMT; Mouser Part Number 490-DS04254203BK-SMT
U1, U2: PCA9685PW/Q900_118; SOP65P640X110-28N
U3: ATmega32U4-M; QFN-44-1EP_7x7mm_P0.5mm_EP5.2x5.2mm
U4: AVR-ISP
Y1: Crystal_GND24; CRYSTAL-SMD-5X3.2-4PAD

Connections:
5V: C2.1, C4.2, C5.2, C16.1, C17.2, C18.1, C19.1, J1.1 (VBUS), J15.1, J16.2, J32.2, J33.2, J34.2, L1.1, R4.2, R5.2, R7.1, R10.2, R11.1, R22.1, R28.2, R29.2, S2.4, U1.28 (VDD), U2.1 (A0), U2.28 (VDD), U3.2 (UVCC), U3.7 (VBUS), U3.14 (VCC), U3.24 (AVCC), U3.34 (VCC), U3.44 (AVCC), U4.VCC
/D+: R2.1, U3.4 (D+)
/D-: R3.1, U3.3 (D-)
/Servo_Multiplexer1_1: R31.2, U1.6 (LED0)
/Servo_Multiplexer1_2: R32.2, U1.7 (LED1)
/Servo_Multiplexer1_3: R33.2, U1.8 (LED2)
/Servo_Multiplexer1_4: R34.2, U1.9 (LED3)
/Servo_Multiplexer1_5: R35.2, U1.10 (LED4)
/Servo_Multiplexer1_6: R36.2, U1.11 (LED5)
/Servo_Multiplexer1_7: R37.2, U1.12 (LED6)
/Servo_Multiplexer1_8: R38.2, U1.13 (LED7)
/Servo_Multiplexer1_9: R39.2, U1.15 (LED8)
/Servo_Multiplexer1_10: R40.2, U1.16 (LED9)
/Servo_Multiplexer1_11: R41.2, U1.17 (LED10)
/Servo_Multiplexer1_12: R42.2, U1.18 (LED11)
/Servo_Multiplexer2_1: R43.2, U2.6 (LED0)
/Servo_Multiplexer2_2: R44.2, U2.7 (LED1)
/Servo_Multiplexer2_3: R45.2, U2.8 (LED2)
/Servo_Multiplexer2_4: R46.2, U2.9 (LED3)
/Servo_Multiplexer2_5: R47.2, U2.10 (LED4)
/Servo_Multiplexer2_6: R48.2, U2.11 (LED5)
/Servo_Multiplexer2_7: R49.2, U2.12 (LED6)
/Servo_Multiplexer2_8: R50.2, U2.13 (LED7)
/Servo_Multiplexer2_9: R51.2, U2.15 (LED8)
/Servo_Multiplexer2_10: R52.2, U2.16 (LED9)
/Servo_Multiplexer2_11: R53.2, U2.17 (LED10)
/Servo_Multiplexer2_12: R54.2, U2.18 (LED11)
/XC+: C1.1, U3.17 (XTAL1), Y1.1
/XC-: C3.1, U3.16 (XTAL2), Y1.3
A0: J32.3, U3.41 (PF0)
A1: J33.3, U3.40 (PF1)
A2: U3.39 (PF4)
A3: U3.38 (PF5)
A4: U3.37 (PF6)
A5: U3.36 (PF7)
A6: U3.25 (PD4)
D0: U3.20 (PD2)
D1: U3.21 (PD3)
D2: J31.1, R5.1, R28.1, U1.27 (SDA), U2.27 (SDA), U3.19 (PD1)
D3: J31.2, R10.1, R29.1, U1.26 (SCL), U2.26 (SCL), U3.18 (PD0)
D5: U3.31 (PC6)
D6: U3.27 (PD7)
D7: U3.1 (PE6)
D8: J15.3, U3.28 (PB4)
D9: J15.4, U3.29 (PB5)
D10: U3.30 (PB6)
D11: U3.12 (PB7)
D12: S2.1, U3.26 (PD6)
D13: U3.32 (PC7)
D14: S3.1 (COM_1), U3.11 (PB3), U4.MISO
D15: S3.3 (COM_2), U3.9 (PB1), U4.SCK
D16: S3.5 (COM_3), U3.10 (PB2), U4.MOSI
D17: R9.1, U3.8 (PB0)
GND: C1.2, C2.2, C3.2, C4.1, C5.1, C6.2 (-), C7.2, C8.2, C9.2 (-), C17.1, C18.2, C19.2, C21.1, C22.2, C23.2, D1.1 (K), D3.1 (K), D4.1 (K), IC1.3 (GND_1), IC1.4 (GND_2), J1.5 (GND), J2.1, J3.1, J4.1, J5.1, J6.1, J7.1, J8.1, J9.1, J10.1, J11.1, J12.1, J13.1, J14.1, J15.2, J16.1, J17.1, J18.1, J19.1, J20.1, J21.1, J22.1, J23.1, J24.1, J25.1, J26.1, J27.1, J28.1, J29.1, J30.1, J32.1, J33.1, J34.1, R1.2, R8.1, R12.2, R13.2, R15.2, R16.2, R17.2, R18.2, R19.2, R20.2, R21.2, R22.2, R23.2, R24.2, R25.2, R26.2, R27.2, R30.2, S1.1, S1.2, S3.2 (NO_1), S3.4 (NO_2), S3.6 (NO_3), U1.14 (VSS), U1.25 (EXTCLK), U2.14 (VSS), U2.25 (EXTCLK), U3.5 (UGND), U3.15 (GND), U3.23 (GND), U3.33 (~HWB/PE2), U3.35 (GND), U3.43 (GND), U3.45 (GND), U4.GND, Y1.2, Y1.4
unnamed: D1.2 (A), R7.2
unnamed: D3.2 (A), R9.2
unnamed: D4.2 (A), R6.1
unnamed: D5.2 (A), Q1.4 (GATE), R15.1
unnamed: C20.1, IC1.7 (BS)
unnamed: IC1.8 (EN), R14.1
unnamed: C16.2, IC1.1 (FB), R11.2, R12.1
unnamed: IC1.2 (FS), R13.1
unnamed: C20.2, IC1.6 (LX), L1.2
unnamed: J1.3 (D+), R2.2
unnamed: J1.2 (D-), R3.2
unnamed: J2.3, R31.1
unnamed: J3.3, R32.1
unnamed: J4.3, R33.1
unnamed: J5.3, R34.1
unnamed: J6.3, R35.1
unnamed: J7.3, R36.1
unnamed: J8.3, R37.1
unnamed: J10.3, R38.1
unnamed: J11.3, R39.1
unnamed: J12.3, R40.1
unnamed: J13.3, R41.1
unnamed: J14.3, R42.1
unnamed: J17.3, R43.1
unnamed: J18.3, R44.1
unnamed: J19.3, R45.1
unnamed: J20.3, R46.1
unnamed: J21.3, R47.1
unnamed: J22.3, R48.1
unnamed: J23.3, R49.1
unnamed: J24.3, R50.1
unnamed: J25.3, R51.1
unnamed: J26.3, R52.1
unnamed: J27.3, R53.1
unnamed: J28.3, R54.1
unnamed: R8.2, S2.2
unnamed: R1.1, U1.23 (*OE)
unnamed: R16.1, U1.1 (A0)
unnamed: R17.1, U1.2 (A1)
unnamed: R18.1, U1.3 (A2)
unnamed: R19.1, U1.4 (A3)
unnamed: R20.1, U1.5 (A4)
unnamed: R21.1, U1.24 (A5)
unnamed: R27.1, U2.23 (*OE)
unnamed: R23.1, U2.2 (A1)
unnamed: R24.1, U2.3 (A2)
unnamed: R25.1, U2.4 (A3)
unnamed: R26.1, U2.5 (A4)
unnamed: R30.1, U2.24 (A5)
unnamed: C7.1, U3.42 (AREF)
unnamed: R6.2, U3.22 (PD5)
unnamed: C8.1, U3.6 (UCAP)
RESET: R4.1, S1.3, S1.4, U3.13 (~RESET), U4.RST
VCC_SERVOBLOCK_1: C6.1 (+), J2.2, J3.2, J4.2, J5.2, J6.2, J7.2, J8.2, J10.2, J11.2, J12.2, J13.2, J14.2, J29.2
VCC_SERVOBLOCK_2: C9.1 (+), J17.2, J18.2, J19.2, J20.2, J21.2, J22.2, J23.2, J24.2, J25.2, J26.2, J27.2, J28.2, J30.2
VIN: C21.2, C22.1, C23.1, D5.1 (K), IC1.5 (IN), J29.3, J30.3, Q1.1 (SOURCE_1), Q1.2 (SOURCE_2), Q1.3 (SOURCE_3), R14.2
Vin before switch: J9.2, Q1.5 (DRAIN_1), Q1.6 (DRAIN_2), Q1.7 (DRAIN_3), Q1.8 (DRAIN_4), Q1.9 (DRAIN_5)

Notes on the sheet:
Servo driver 1
5V Power supply
Microcontroller
Servo driver 2
Power supply
Servo outputs

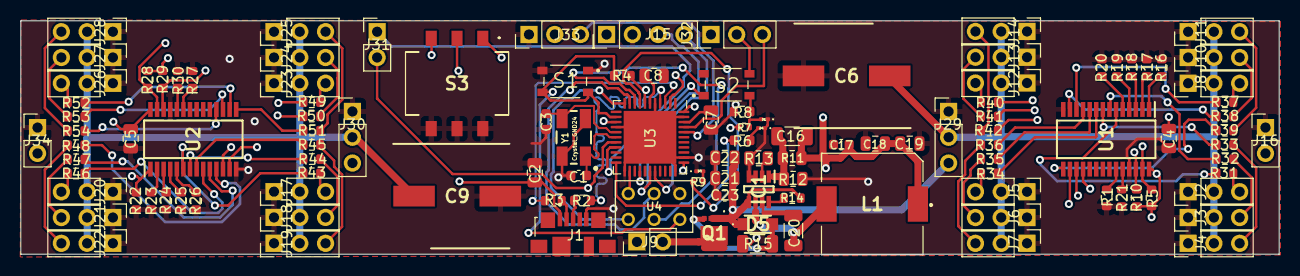
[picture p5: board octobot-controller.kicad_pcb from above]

Board: 4 copper layers, 124.0 x 23.0 mm, 120 parts (0 on the bottom side), 98 nets.

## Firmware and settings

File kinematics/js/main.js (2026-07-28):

// main.js — scene bootstrap, app state, interaction, render loop
import * as THREE from 'three';
import { OrbitControls } from 'three/addons/controls/OrbitControls.js';
import { TransformControls } from 'three/addons/controls/TransformControls.js';
import { RoomEnvironment } from 'three/addons/environments/RoomEnvironment.js';
import { createResolutionGovernor, createContactShadow } from './perf.js';
import { Chain } from './chain.js';
import { GaitEngine } from './gait.js';
import { RigBinding } from './binding.js';
import { setModelZUp } from './loader.js';
import { LIMITS } from './octorig.js';
import { initUI } from './ui.js';

const CHAIN_COLORS = [0xf2a33c, 0x53d5e6, 0xe561a8, 0x46c98c, 0xb08cff, 0xe5484d];

const App = {
  scene: null, camera: null, renderer: null,
  orbit: null, tcontrols: null,
  chains: [],
  activeChain: null,
  selectedJoint: null, // { chain, index } | null
  models: [],
  mode: 'solve',       // 'solve' | 'build'
  collisionOpts: { models: true, self: true, floor: true },
  ui: null,
  fps: 0,
};
window.__IK_APP = App; // console handle for debugging

const BG = 0x0d0f12;

// --- scene -----------------------------------------------------------------

function initScene() {
  const viewport = document.getElementById('viewport');
  const renderer = new THREE.WebGLRenderer({ antialias: true, powerPreference: 'high-performance' });
  renderer.setSize(window.innerWidth, window.innerHeight);
  App.govern = createResolutionGovernor(renderer); // owns the pixel ratio
  renderer.toneMapping = THREE.ACESFilmicToneMapping;
  renderer.toneMappingExposure = 0.95;
  viewport.appendChild(renderer.domElement);

  const scene = new THREE.Scene();
  scene.background = new THREE.Color(BG);
  scene.fog = new THREE.Fog(BG, 22, 55);

  const camera = new THREE.PerspectiveCamera(50, window.innerWidth / window.innerHeight, 0.05, 200);
  camera.position.set(6.5, 4.5, 7.5);

  const orbit = new OrbitControls(camera, renderer.domElement);
  orbit.target.set(0, 1.6, 0);
  orbit.enableDamping = true;
  orbit.dampingFactor = 0.08;
  orbit.maxPolarAngle = Math.PI * 0.52;
  orbit.minDistance = 1;
  orbit.maxDistance = 40;

  // The printed parts are dark, low-metalness PBR. Without an environment to
  // sample they render as a flat silhouette, so a prefiltered room probe carries
  // the ambient term and the three directional lights only have to carve shape.
  const pmrem = new THREE.PMREMGenerator(renderer);
  pmrem.compileEquirectangularShader();
  scene.environment = pmrem.fromScene(new RoomEnvironment(), 0.04).texture;
  pmrem.dispose();

  // Near-neutral rig: a warm key against a cooler sky and rim. Above about 1.2
  // on the key the chassis blows out to white.
  scene.add(new THREE.HemisphereLight(0xb4bcc4, 0x1a1410, 0.24));
  for (const [color, intensity, x, y, z] of [
    [0xfff2dd, 1.15, 6, 10, 4],    // key
    [0xd2d8de, 0.28, -5, 3, 8],    // fill
    [0xc8d2da, 0.45, -8, 4, -6],   // rim
  ]) {
    const light = new THREE.DirectionalLight(color, intensity);
    light.position.set(x, y, z);
    scene.add(light);
  }

  // Two grids: metre squares over a finer 200 mm mesh, for a sense of scale.
  const grid = new THREE.GridHelper(30, 30, 0x2c333d, 0x1b2028);
  grid.material.transparent = true;
  grid.material.opacity = 0.8;
  scene.add(grid);
  const gridFine = new THREE.GridHelper(30, 150, 0x161b21, 0x14181e);
  gridFine.position.y = -0.002;
  scene.add(gridFine);

  const axes = new THREE.AxesHelper(0.8);
  axes.position.y = 0.001;
  scene.add(axes);

  // grounds the robot without a shadow-map pass over a 12 MB mesh
  App.contactShadow = createContactShadow(THREE, { size: 3.2, opacity: 0.3 });
  App.contactShadow.visible = false;
  scene.add(App.contactShadow);

  // transform gizmo
  const tcontrols = new TransformControls(camera, renderer.domElement);
  tcontrols.size = 0.75;
  tcontrols.addEventListener('dragging-changed', e => {
    orbit.enabled = !e.value;
    // the gizmo clears `dragging` before our pointerup fires, which would make
    // the release read as a click (deselecting / placing a stray joint)
    if (!e.value) App.gizmoReleasedAt = performance.now();
  });
  tcontrols.addEventListener('objectChange', onGizmoChange);
  scene.add(tcontrols);

  // Anything that can change what the viewport shows re-arms the render loop.
  // The document-level listeners cover every panel control in one place, which
  // beats threading an invalidate() call through each handler.
  orbit.addEventListener('change', invalidate);
  for (const type of ['pointerdown', 'pointermove', 'wheel', 'input', 'change', 'keydown']) {
    document.addEventListener(type, invalidate, { passive: true, capture: true });
  }

  let resizeTimer = 0;
  window.addEventListener('resize', () => {
    // dragging a window edge fires this continuously, and each call reallocates
    // the drawing buffer
    clearTimeout(resizeTimer);
    resizeTimer = setTimeout(() => {
      camera.aspect = window.innerWidth / window.innerHeight;
      camera.updateProjectionMatrix();
      renderer.setSize(window.innerWidth, window.innerHeight);
      invalidate();
    }, 80);
  });

  Object.assign(App, { scene, camera, renderer, orbit, tcontrols });
}

// --- framing ---------------------------------------------------------------

/**
 * The part of the window no panel is covering, in CSS pixels. The chrome is
 * fixed-position over a full-bleed canvas, so a model centred in the window is
 * not centred in the space the user can actually see.
 */
function clearViewRect() {
  const W = window.innerWidth, H = window.innerHeight;
  const shown = id => {
    const el = document.getElementById(id);
    return el && !el.classList.contains('collapsed') ? el.getBoundingClientRect() : null;
  };
  let x = 0, right = W, y = 0, bottom = H;
  const left = shown('sidebar');
  if (left) x = left.right + 12;
  const rightCol = shown('sidebar-right');
  if (rightCol) right = rightCol.left - 12;
  const bar = document.getElementById('topbar')?.getBoundingClientRect();
  if (bar) y = bar.bottom;
  const foot = document.getElementById('telemetry')?.getBoundingClientRect();
  if (foot) bottom = foot.top;

  const w = right - x, h = bottom - y;
  // a small window leaves nothing usable free — frame against the whole viewport
  return (w < 240 || h < 240) ? { x: 0, y: 0, w: W, h: H } : { x, y, w, h };
}

/**
 * Half-extent of the geometry under `roots` along each of `axes`, measured from
 * `centre`. Vertices are sampled rather than read in full: this runs on every
 * re-frame, and a few dozen points per mesh place the silhouette to well inside
 * the framing margin.
 */
function extentsAlong(roots, centre, axes) {
  const out = axes.map(() => 0);
  const v = new THREE.Vector3();
  for (const root of roots) {
    if (!root) continue;
    root.updateMatrixWorld(true);
    root.traverse(o => {
      const pos = o.isMesh && o.geometry?.attributes?.position;
      if (!pos) return;
      const stride = Math.max(1, Math.floor(pos.count / 48));
      for (let i = 0; i < pos.count; i += stride) {
        v.fromBufferAttribute(pos, i).applyMatrix4(o.matrixWorld).sub(centre);
        for (let a = 0; a < axes.length; a++) {
          out[a] = Math.max(out[a], Math.abs(v.dot(axes[a])));
        }
      }
    });
  }
  return out;
}

/**
 * Point the camera at `objects` and pull back far enough to hold all of them
 * inside the clear view rect. The rig comes from CAD, so its size is only known
 * once the GLB has parsed; a hardcoded start pose leaves the robot small and
 * off-centre.
 */
export function frameModel(objects, { padding = 1.08 } = {}) {
  const { camera, orbit } = App;
  const roots = (Array.isArray(objects) ? objects : [objects]).filter(Boolean);
  const box = new THREE.Box3();
  for (const o of roots) box.union(new THREE.Box3().setFromObject(o));
  if (box.isEmpty()) return;

  const center = box.getCenter(new THREE.Vector3());
  const view = clearViewRect();
  const W = window.innerWidth, H = window.innerHeight;

  // full-frame half-angles, then the same angles narrowed to the clear rect
  const halfV = THREE.MathUtils.degToRad(camera.fov) / 2;
  const halfH = Math.atan(Math.tan(halfV) * camera.aspect);
  const fitV = Math.atan(Math.tan(halfV) * view.h / H);
  const fitH = Math.atan(Math.tan(halfH) * view.w / W);

  // Fit the geometry itself. The octobot is a wide flat disc, so both its bounding
  // sphere and its bounding box stick out well past anything the camera sees, and
  // fitting either leaves the robot small in the middle of an empty frame.
  const dir = new THREE.Vector3(0.62, 0.42, 0.66).normalize();
  const basis = new THREE.Matrix4().lookAt(_fv.copy(center).add(dir), center, camera.up);
  const bx = new THREE.Vector3().setFromMatrixColumn(basis, 0);
  const by = new THREE.Vector3().setFromMatrixColumn(basis, 1);
  const ex = extentsAlong(roots, center, [bx, by, dir]);
  const dist = (Math.max(ex[0] / Math.tan(fitH), ex[1] / Math.tan(fitV)) + ex[2]) * padding;

  orbit.target.copy(center);
  camera.position.copy(center).addScaledVector(dir, dist);
  orbit.update();               // aims the camera, so its basis is now valid
  camera.updateMatrixWorld();

  // Move the camera sideways until the model sits at the centre of the clear rect
  // rather than the centre of the window. Shifting the camera and its target
  // together displaces the subject by the same amount in the opposite direction.
  const ndcX = (view.x + view.w / 2) / W * 2 - 1;
  const ndcY = 1 - (view.y + view.h / 2) / H * 2;
  const camBasis = camera.matrixWorld.elements;
  const shift = new THREE.Vector3(camBasis[0], camBasis[1], camBasis[2])
    .multiplyScalar(-ndcX * Math.tan(halfH) * dist)
    .addScaledVector(new THREE.Vector3(camBasis[4], camBasis[5], camBasis[6]),
                     -ndcY * Math.tan(halfV) * dist);
  orbit.target.add(shift);
  camera.position.add(shift);

  camera.near = Math.max(0.01, dist / 200);
  camera.far = dist * 12;
  camera.updateProjectionMatrix();
  orbit.update();
  invalidate();
}

// --- gizmo / modes ---------------------------------------------------------

function onGizmoChange() {
  const obj = App.tcontrols.object;
  if (!obj) return;
  if (obj.userData?.kind === 'joint') {
    const { chain, index } = obj.userData;
    chain.setJointPos(index, obj.position);
    chain.snapTargetToEE();
    App.ui?.softRefreshJoints();
  } else {
    // target marker moved
    const chain = App.chains.find(c => c.targetGroup === obj);
    if (chain) {
      chain.target.copy(obj.position);
      chain.targetDirty = true;
    }
  }
}

export function setMode(mode) {
  App.mode = mode;
  App.tcontrols.detach();
  if (mode === 'solve') {
    if (App.activeChain && App.activeChain.joints.length >= 2) {
      App.activeChain.snapTargetToEE();
      App.tcontrols.attach(App.activeChain.targetGroup);
    }
  } else if (mode === 'build') {
    if (App.selectedJoint) {
      App.tcontrols.attach(App.selectedJoint.chain.joints[App.selectedJoint.index].mesh);
    }
  }
  App.ui?.onModeChanged();
}

export function setActiveChain(chain) {
  App.activeChain = chain;
  selectJoint(null);
  if (App.mode === 'solve') setMode('solve'); // re-attach gizmo to new target
  App.ui?.refreshAll();
}

export function selectJoint(sel) {
  if (App.selectedJoint) App.selectedJoint.chain.setSelectedJoint(-1);
  App.selectedJoint = sel;
  if (sel) {
    sel.chain.setSelectedJoint(sel.index);
    if (App.activeChain !== sel.chain) {
      App.activeChain = sel.chain;
    }
    if (App.mode === 'build') {
      App.tcontrols.attach(sel.chain.joints[sel.index].mesh);
    }
  } else if (App.mode === 'build') {
    App.tcontrols.detach();
  }
  App.ui?.refreshAll();
}

/** Legs are only ever created by the octobot auto-rig, never by hand. */
function deleteChain(chain) {
  const i = App.chains.indexOf(chain);
  if (i === -1) return;
  // stop anything still driving this chain, or it dereferences a disposed chain
  if (App.gait?.active && App.gait.legs.some(l => l.chain === chain)) App.gait.stop();
  if (App.binding.links.some(l => l.chain === chain)) App.binding.clear();
  if (App.selectedJoint?.chain === chain) App.selectedJoint = null;
  if (App.tcontrols.object && (App.tcontrols.object.userData?.chain === chain || App.tcontrols.object === chain.targetGroup)) {
    App.tcontrols.detach();
  }
  for (const m of App.models) if (m.attachedTo?.chain === chain) m.attachedTo = null;
  chain.dispose();
  App.chains.splice(i, 1);
  if (App.activeChain === chain) App.activeChain = App.chains[App.chains.length - 1] ?? null;
  if (App.mode === 'solve') setMode('solve');
  App.ui?.refreshAll();
}

// --- gait auto-rig ---------------------------------------------------------

/**
 * Find the 8 (or however many) feet of a loaded walker model by clustering
 * vertices that touch the ground plane. Returns world-space foot centroids.
 */
function detectFeet(model) {
  model.group.updateMatrixWorld(true);
  const contacts = [];
  for (const mesh of model.meshes) {
    const pos = mesh.geometry.attributes.position;
    const stride = Math.max(1, Math.floor(pos.count / 20000)); // sample big meshes
    for (let i = 0; i < pos.count; i += stride) {
      _fv.fromBufferAttribute(pos, i).applyMatrix4(mesh.matrixWorld);
      if (_fv.y < 0.07) contacts.push(_fv.clone());
    }
  }
  // greedy XZ clustering
  const clusters = [];
  for (const p of contacts) {
    let best = null, bestD = 0.34;
    for (const cl of clusters) {
      const d = Math.hypot(p.x - cl.c.x, p.z - cl.c.z);
      if (d < bestD) { best = cl; bestD = d; }
    }
    if (best) {
      best.n++;
      best.c.lerp(p, 1 / best.n);
    } else {
      clusters.push({ c: p.clone(), n: 1 });
    }
  }
  clusters.sort((a, b) => b.n - a.n);
  return clusters.slice(0, 8).filter(cl => cl.n >= 3).map(cl => new THREE.Vector3(cl.c.x, 0, cl.c.z));
}

const _fv = new THREE.Vector3();

/**
 * Rig the octobot model: one hip-yaw → shoulder → knee → foot chain per
 * detected foot, then bind the mesh parts to the bones. Only runs for the
 * octobot (name match + 6..8 feet on the floor). Returns result or null.
 */
export function maybeRigOctobot(model) {
  if (!model || !/octo/i.test(model.name)) return null;
  App.binding.clear(); // restore mesh to rest pose before measuring it
  let feet = detectFeet(model);
  // a CAD export lying on its side has no feet on the floor — stand it up
  if (feet.length < 6 && !model.zUp) {
    setModelZUp(model, true);
    feet = detectFeet(model);
    if (feet.length < 6) setModelZUp(model, false);
  }
  if (feet.length < 6) return null; // e.g. the single-leg model — leave unrigged

  const center = new THREE.Vector3();
  const box = new THREE.Box3().setFromObject(model.group);
  box.getCenter(center);

  // Pivots come from the CAD occurrences. Each leg has three servos, and the
  // joint axis runs through the servo shaft rather than the body centre. The
  // shaft is where the servo's bounding box overlaps the link it drives
  // (art_1/2/3), because that link wraps the shaft and bearing coaxially.
  let occRoot = model._rot;
  while (occRoot.children.length === 1) occRoot = occRoot.children[0];
  const servos = [];   // { center, box, node }
  const arts = [[], [], []]; // art_1 / art_2 / art_3: { center, box, node }
  const others = [];   // remaining occurrences: { center, node }
  for (const node of occRoot.children) {
    const name = node.name ?? '';
    const isServo = /servo/i.test(name);
    const artM = name.match(/art_([123])/i);
    const box = new THREE.Box3().setFromObject(node);
    if (box.isEmpty()) continue;
    const entry = { center: box.getCenter(new THREE.Vector3()), box, node };
    if (isServo) servos.push(entry);
    else if (artM) arts[+artM[1] - 1].push(entry);
    else others.push(entry);
  }
  const _isect = new THREE.Box3();
  // joint pivot = center of the servo∩link overlap (the shaft/bearing region)
  const shaftPivot = (servo, artList, legAng, angOfFn) => {
    let best = null, bestA = Infinity;
    for (const a of artList) {
      const d = Math.abs(THREE.MathUtils.euclideanModulo(angOfFn(a.center) - legAng + Math.PI, Math.PI * 2) - Math.PI);
      if (d < bestA) { bestA = d; best = a; }
    }
    if (best && bestA < 0.33) {
      _isect.copy(servo.box).intersect(best.box);
      if (!_isect.isEmpty()) return _isect.getCenter(new THREE.Vector3());
    }
    return servo.center.clone();
  };
  const angOf = p => Math.atan2(p.z - center.z, p.x - center.x);
  const angDiff = (a, b) => Math.abs(THREE.MathUtils.euclideanModulo(a - b + Math.PI, Math.PI * 2) - Math.PI);
  const radialOf = p => Math.hypot(p.x - center.x, p.z - center.z);

  App.gait.stop();
  for (const c of [...App.chains]) deleteChain(c);

  // Two servo mounting styles on this robot:
  //   hip — inverted, the horn is anchored to the chassis, so the servo body and
  //     its casing rotate on the spot with the coxa.
  //   shoulder and knee — conventional, the servo is bolted to the link before
  //     the joint and only the part on the horn rotates.
  const nodeAssign = new Map(); // node → { group: 'body'|boneIndex, d }
  const claim = (node, group, d) => {
    const prev = nodeAssign.get(node);
    if (!prev || d < prev.d) nodeAssign.set(node, { group, d });
  };
  // servo horn sub-meshes that bind to a different bone than their servo body
  const servoHeadNodes = [];

  feet.forEach(foot => {
    const fAng = angOf(foot);
    // this leg's servos: same bearing as the foot, sorted hip → knee by radius
    const legServos = servos
      .filter(s => angDiff(angOf(s.center), fAng) < 0.28)
      .sort((a, b) => radialOf(a.center) - radialOf(b.center));
    if (legServos.length < 3) return; // can't place this leg reliably

    const chain = new Chain(App.scene, CHAIN_COLORS[App.chains.length % CHAIN_COLORS.length]);
    chain.setVisualScale(0.45); // keep the mesh readable — slim bones
    App.chains.push(chain);
    // pivots on the actual shaft/bearing axes: servo ∩ driven link
    const mount = shaftPivot(legServos[0], arts[0], fAng, angOf);
    const shoulder = shaftPivot(legServos[1], arts[1], fAng, angOf);
    const knee = shaftPivot(legServos[2], arts[2], fAng, angOf);
    // Every part follows the link it is screwed to, which is the link its mesh
    // overlaps most. That covers both mount styles without a special case: the
    // hip servo body overlaps the coxa and turns with it, the knee servo body
    // overlaps the femur and stays put as the tibia bends.
    const legArts = arts.map(list => {
      let best = null, bestA = 0.33;
      for (const a of list) {
        const d = angDiff(angOf(a.center), fAng);
        if (d < bestA) { bestA = d; best = a; }
      }
      return best ? { ...best, bearingErr: bestA } : null;
    });
    // Claim the coxa, femur and tibia for this leg explicitly. A bare bone index
    // would leave binding.js to resolve the leg from its bearing heuristic, and a
    // miss there sends the link to a neighbouring leg while its servo, claimed
    // exactly, stays behind. Scoring by bearing error means the closer leg keeps
    // a link both reach for.
    legArts.forEach((a, i) => {
      if (a) claim(a.node, { chain, bone: i }, -1e6 + a.bearingErr);
    });
    const overlapVol = (a, b) => {
      const x = Math.min(a.max.x, b.max.x) - Math.max(a.min.x, b.min.x);
      const y = Math.min(a.max.y, b.max.y) - Math.max(a.min.y, b.min.y);
      const z = Math.min(a.max.z, b.max.z) - Math.max(a.min.z, b.min.z);
      return (x > 0 && y > 0 && z > 0) ? x * y * z : 0;
    };
    // best articulation bone by mesh overlap; returns -1 if no meaningful overlap
    const overlapBone = box => {
      let bestVol = 0, bestIdx = -1;
      legArts.forEach((a, k) => {
        if (!a) return;
        const v = overlapVol(box, a.box);
        if (v > bestVol) { bestVol = v; bestIdx = k; }
      });
      const s = box.max.clone().sub(box.min);
      const ownVol = Math.max(s.x * s.y * s.z, 1e-9);
      return (bestIdx >= 0 && bestVol > 0.12 * ownVol) ? { bone: bestIdx, vol: bestVol } : null;
    };
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

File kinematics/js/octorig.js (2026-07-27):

// octorig.js — loads the octobot GLB and builds a mechanically-true rig:
// a real transform HIERARCHY (chassis → hip → shoulder → knee) so parts can
// never detach, with exact closed-form IK per leg (yaw + 2-link planar).
//
// Servo split (validated against the physical build):
//   hip:      servo body + casing rotate with the coxa (inverted mount),
//             servo head stays on the chassis
//   shoulder: servo body rides the femur, head stays seated in the coxa bearing
//   knee:     servo body stays on the femur, head rotates with the tibia
import * as THREE from 'three';
import { GLTFLoader } from 'three/addons/loaders/GLTFLoader.js';
import { fetchArrayBuffer } from './boot.js';

const UP = new THREE.Vector3(0, 1, 0);
const V = (x = 0, y = 0, z = 0) => new THREE.Vector3(x, y, z);

/**
 * Joint limits (radians from the rest pose). These are the ranges the physical
 * linkage can sweep without the brackets fouling — not the servo's full travel.
 *
 * They were widened to ±90° at one point, and that is what produced the folded,
 * curled leg poses: around obstacles 43–55% of frames had a joint past 60°, with
 * both shoulder and knee pinned at the ±90° stop. Measured side by side, the
 * tighter values cost nothing and fix it — identical climb heights (0.22 / 0.43),
 * walking distance within 3%, and strictly better everywhere else:
 *
 *            frames past 60°   clip frames   deepest penetration
 *   ±90°         43-55%         0.3 / 2.4%      37 / 153 mm
 *   these          0%           0.0 / 1.2%       7 /  61 mm
 */
export const LIMITS = { yaw: 0.55, shoulder: Math.PI / 2, knee: Math.PI / 2 };
const clamp = THREE.MathUtils.clamp;
const wrapPi = a => Math.atan2(Math.sin(a), Math.cos(a));
const angDiff = (a, b) => Math.abs(THREE.MathUtils.euclideanModulo(a - b + Math.PI, Math.PI * 2) - Math.PI);

async function loadGLB(url, onProgress) {
  const buf = await fetchArrayBuffer(url, onProgress);
  return new Promise((ok, err) => new GLTFLoader().parse(buf, '', ok, err));
}

function worldBox(o) { return new THREE.Box3().setFromObject(o); }

function overlapVol(a, b) {
  const x = Math.min(a.max.x, b.max.x) - Math.max(a.min.x, b.min.x);
  const y = Math.min(a.max.y, b.max.y) - Math.max(a.min.y, b.min.y);
  const z = Math.min(a.max.z, b.max.z) - Math.max(a.min.z, b.min.z);
  return (x > 0 && y > 0 && z > 0) ? x * y * z : 0;
}

/** Cluster ground-contact vertices into foot positions. */
function detectFeet(root) {
  root.updateMatrixWorld(true);
  // cluster radius scales with the model so smaller walkers don't merge feet
  const span = worldBox(root).getSize(V());
  const clusterR = Math.max(0.08, Math.max(span.x, span.z) * 0.11);
  const v = V();
  const contacts = [];
  root.traverse(m => {
    if (!m.isMesh) return;
    const pos = m.geometry.attributes.position;
    const stride = Math.max(1, Math.floor(pos.count / 20000));
    for (let i = 0; i < pos.count; i += stride) {
      v.fromBufferAttribute(pos, i).applyMatrix4(m.matrixWorld);
      if (v.y < 0.07) contacts.push(v.clone());
    }
  });
  const clusters = [];
  for (const p of contacts) {
    let best = null, bd = clusterR;
    for (const cl of clusters) {
      const d = Math.hypot(p.x - cl.c.x, p.z - cl.c.z);
      if (d < bd) { bd = d; best = cl; }
    }
    if (best) { best.n++; best.c.lerp(p, 1 / best.n); }
    else clusters.push({ c: p.clone(), n: 1 });
  }
  clusters.sort((a, b) => b.n - a.n);
  return clusters.slice(0, 8).filter(c => c.n >= 3).map(c => V(c.c.x, 0, c.c.z));
}

export async function loadOctobot(url, scene, onProgress) {
  const gltf = await loadGLB(url, onProgress);
  const g = gltf.scene;
  g.rotation.x = -Math.PI / 2; // CAD Z-up → scene Y-up

  const wrap = new THREE.Group();
  wrap.add(g);
  const root = new THREE.Group(); // the chassis / body node — move this to move the robot
  root.name = 'octobot';
  root.add(wrap);
  scene.add(root);
  root.updateMatrixWorld(true);

  // normalize: largest dimension = 3 units, centered, base on y=0
  let box = worldBox(wrap);
  const size = box.getSize(V());
  wrap.scale.setScalar(3 / Math.max(size.x, size.y, size.z));
  root.updateMatrixWorld(true);
  box = worldBox(wrap);
  const bc = box.getCenter(V());
  wrap.position.set(-bc.x, -box.min.y, -bc.z);
  root.updateMatrixWorld(true);

  // assembly root = deepest single-child descent
  let occRoot = g;
  while (occRoot.children.length === 1) occRoot = occRoot.children[0];

  // collect occurrences (world boxes, post-normalization)
  const servos = [], arts = [[], [], []], others = [];
  for (const node of occRoot.children) {
    const name = node.name ?? '';
    const b = worldBox(node);
    if (b.isEmpty()) continue;
    const entry = { node, box: b, center: b.getCenter(V()) };
    const artM = name.match(/art_([123])/i);
    if (/servo/i.test(name)) servos.push(entry);
    else if (artM) arts[+artM[1] - 1].push(entry);
    else others.push(entry);
  }

  const feet = detectFeet(root);
  if (feet.length < 6) throw new Error('octobot feet not found (' + feet.length + ')');
  const center = worldBox(root).getCenter(V());
  const angOf = p => Math.atan2(p.z - center.z, p.x - center.x);
  const radOf = p => Math.hypot(p.x - center.x, p.z - center.z);

  // ---------------------------------------------------------------- legs
  const legs = [];
  const claims = new Map(); // occurrence node → { targetNode, score }
  const claim = (node, targetNode, score) => {
    const prev = claims.get(node);
    if (!prev || score < prev.score) claims.set(node, { targetNode, score });
  };
  const meshVol = m => {
    const b = worldBox(m);
    if (b.isEmpty()) return 0;
    const s = b.getSize(V());
    return s.x * s.y * s.z;
  };

  for (const foot of feet) {
    const fAng = angOf(foot);
    const legServos = servos
      .filter(s => angDiff(angOf(s.center), fAng) < 0.28)
      .sort((a, b) => radOf(a.center) - radOf(b.center));
    if (legServos.length < 3) continue;
    const legArts = arts.map(list => {
      let best = null, ba = 0.33;
      for (const a of list) {
        const d = angDiff(angOf(a.center), fAng);
        if (d < ba) { ba = d; best = a; }
      }
      return best;
    });
    // split each servo occurrence into BODY (largest mesh) + HEADS (the rest)
    const servoKids = legServos.slice(0, 3).map(sv => {
      const kids = [];
      sv.node.traverse(o => { if (o.isMesh) kids.push(o); });
      kids.sort((a, b) => meshVol(b) - meshVol(a));
      return kids;
    });
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

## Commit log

2026-07-27 Octobot: mechanical, control board and kinematics workbench
    Eight-legged, 24-servo walking robot. This repository holds the CAD exports,
    the KiCad project for the servo control board, and a browser workbench that
    rigs the CAD model and solves its inverse kinematics.
    - kinematics/ Three.js workbench and locomotion sandbox, no build step
    - hardware/ KiCad 7 project: ATmega32U4 + 2x PCA9685 + SY8303 buck
    - mechanical/ chassis and leg STEP exports, zipped
    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
    [octobot-controller-CuBottom.gbr, octobot-controller-CuIn1.gbr, octobot-controller-CuIn2.gbr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]
2026-07-27 ci: publish the kinematics workbench to GitHub Pages
    The workbench is static — plain ES modules with Three.js from a CDN — so it
    needs no build step. The workflow uploads kinematics/ as the Pages artifact so
    the site root is the workbench itself.
2026-07-27 Dark metallic finish, adaptive resolution, and a generated BOM
    Rendering:
    - Remap the CAD materials to a dark metallic grey. The Fusion export came out
    near-white, and the printed parts are dark. Applied before the auto-rig runs,
    because rigging reparents meshes out of the group a later traverse would walk.
    - Add a soft contact shadow under the robot instead of a shadow-map pass.
    Performance:
    - Add a resolution governor that trades pixel ratio for frame rate. It settles
    within a second and holds, so it will not oscillate during a gait. Verified
    it drops 1.0 -> 0.75 under software rendering.
    - Request a high-performance GPU and debounce the resize handler, which was
    real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
    [main.js]
2026-07-28 hardware: one fabrication package, and a BOM read from the layout
    The board house package was 16 loose gerbers, a separate drill set, a CPL
    export and a zip that duplicated all of it. Replace that with the single
    octobot-controller-fabrication.zip the house was actually sent, plus the
    placement CSV, and re-export the BOM from the current layout.
    gen_bom.py now reads the BOM out of octobot-controller.kicad_pcb rather than
    trusting the export, and --check re-groups the fabrication BOM the same way
    and compares it designator by designator:
    python hardware/tools/gen_bom.py --check
    120 placements match octobot-controller-bom.csv exactly.
    [octobot-controller-CuBottom.gbr, octobot-controller-CuIn1.gbr, octobot-controller-CuIn2.gbr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]
2026-07-28 docs, kinematics: generated BOM, HC-12 header, and a working telemetry HUD
    Land the generated BOM in docs/bom.md and in the README, and document the
    4-pin J15 header as what it is: 5 V, GND, D8 and D9 to an HC-12 radio, on a
    software UART so the hardware USART stays free.
    The playground HUD was dead. Telemetry called a setText() helper that only
    existed in ui.js, so every tick threw ReferenceError and froze the servo
    angles, the foot contact table and the block count on load. Define the
    helper in playground.js next to the other module-local ones.
    The status bar also printed raw gait state names. STATE_LABEL was missing
    BOOT, GUARD and SETTLE, so the bar read SETTLE next to Walkin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
    [main.js]
2026-08-29 Plainer wording in the README and the BOM summary line The summary line is generated, so the wording change goes in gen_bom.py as well or the next regeneration puts the dash back.
2026-09-26 docs: servo voltage, step-climb shoulder limit, and gait-log checks
    From the OmniLink team's simulation of the MG996R at 4.8 V and 6.0 V. Recommends 6 V servo rails, records the torque margin and the unmeasured mass it depends on, and notes that a stalled gait still reports finished.
2026-11-06 docs: correct the SY8303 role and record the built power setup
    The SY8303 makes the 5 V logic rail and does not supply the servo rails. The rail headers take a solder bridge, not a jumper. The built robot runs on two 2-cell 9000 mAh LiPo packs with XT60 connectors, each through its own step-down converter.
